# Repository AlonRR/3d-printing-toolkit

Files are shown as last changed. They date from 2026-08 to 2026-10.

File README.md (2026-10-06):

# 3D printing toolkit — profiles, design rules, part verification

Print-process engineering around a single **Prusa MK3S+**, treated as production equipment rather
than a hobby printer. Three things live here:

| | |
|---|---|
| **Tuned slicer profiles** | 20 filament + 10 print + 1 printer preset, every number traced to a vendor datasheet or to a measurement on this machine |
| **Design rules** | FDM constraints calibrated to *this* machine's measured extrusion width, not its nozzle diameter |
| **Part verification** | A pipeline that renders, asserts, checks manifold, slices, and cross-checks a model against the profile it was actually sliced with |

Every figure here is either read out of this repo's own sliced output or measured on the machine.
Where a number is inherited or assumed rather than measured, it says so — that distinction is the
point of most of these documents.

---

## ⚠️ Read this first if you are about to write a profile

**PrusaSlicer does not resolve `inherits` in a hand-written user preset.** Missing keys take the
system *default*, not the parent's value — silently, while slicing still succeeds. A correct preset
has about 85 keys. Full explanation and the fix:
[`slicer/filament/inslogic/README.md`](slicer/filament/inslogic/README.md).

Two more from the same day, each of which cost a round trip:

- **A resolved chain drags `renamed_from` into the child**, so four PETG profiles each ended up
  claiming to *be* the renamed `Generic PET`.
- **`Prusament PETG` excludes 0.6 nozzles** in its compatibility condition, so anything inheriting
  it vanishes from the filament list on a 0.6 — which is why every PETG profile here inherits
  `Generic PETG` instead.

---

## What's in the repo

| Path | |
|---|---|
| [`slicer/filament/inslogic/`](slicer/filament/inslogic/) | Profiles derived from real vendor datasheets — ASA, TPU 95A, PLA Pro, PETG Pro |
| [`slicer/filament/yasin3d/`](slicer/filament/yasin3d/) | A vendor that publishes **no** datasheet. Labelled as a starting point, not a calibration |
| [`slicer/filament/unbranded/`](slicer/filament/unbranded/) | Filament with **no manufacturer at all** — the SKU is its only identity, so the SKU is in the filename |
| [`slicer/filament/ultrafuse/`](slicer/filament/ultrafuse/) | A user copy of a system preset, inherited and not validated here |
| [`slicer/print/`](slicer/print/) | The custom print profiles. ⚠️ One, `…lightning`, has `spiral_vase = 1` baked in — deliberate and documented, but it will surprise you if selected blind |
| [`slicer/printer/`](slicer/printer/) | The printer preset itself |
| [`slicer/reference/`](slicer/reference/) | Vendor data transcribed to Markdown, with what was taken and what was overridden |
| [`scripts/flatten_profiles.py`](scripts/flatten_profiles.py) | Regenerates filament profiles from the vendor chain, because of the `inherits` trap above |
| [`scripts/scad-check.sh`](scripts/scad-check.sh) | Verify a part end to end — render, asserts, manifold, slice — and cross-check its declared parameters against the profile actually used |
| [`scripts/scad-preview.sh`](scripts/scad-preview.sh) | Previews and cross-sections. Sections import the **exported STL**, so an export bug cannot hide behind a correct-looking render |
| [`models/`](models/) | Parametric OpenSCAD sources. The `.scad` is the artefact; STLs are build output and are not tracked |
| [`models/lib/axes.scad`](models/lib/axes.scad) | The xyz arrows **every rendered figure carries** — red +x, green +y, blue +z, the drawn model's own axes — so a reading taken on a part in hand ("0.7 mm loose in x") maps onto the model without guessing |
| [`docs/`](docs/) | The written material — see *Documentation* below |

## What's deliberately *not* here

- **Models and G-code.** STL, 3MF and G-code are large binaries and git is the wrong tool for them.
  `.gitignore` enforces it.
- **Physical-printer configs.** They hold PrusaLink API keys in plaintext. Also gitignored.
- **The parametric CAD library** — a separate project.
- **The heated drybox and desiccant module.** Their documents, firmware and models moved to a
  repository of their own in September 2026, once that work had grown into a project rather than a
  corner of this one. It is not public, so there is no link to give. What stayed here is the material
  the two share: the annealing page, the mechanical-design-review checklist, `scad-check.sh` and
  `scad-controls.sh`.
- **Procurement.** Prices that carry an argument stay; order references, vendors and what was paid
  belong in an inventory system, not a code repo.

---

## Slicer profiles — `slicer/`

**The difference between the vendors is the point.** Inslogic publishes real technical datasheets,
so those profiles derive every temperature, flow and cooling figure from a documented source.
Yasin3D publishes nothing, and one filament here has no manufacturer at all. Those profiles are
generic values with a name attached, and each directory's README records which is which, so nobody
mistakes an assumption for a measurement.

### A defect worth knowing about

The ASA profile asks for a 15 second minimum layer time. **`min_print_speed` silently caps it at
5 seconds** — the slicer does not warn you, and the symptom is poor small-layer cooling that reads
as a temperature problem. [`docs/asa-print-quality.md`](docs/asa-print-quality.md) covers this and
the rest of the ASA tuning, ordered by payoff.

## Design rules — `docs/fdm-design-rules.md`

The governing dimension on this machine is the **0.45 mm extrusion width, not the 0.4 mm nozzle**,
so wall thicknesses quantise to multiples of 0.45. Designing to the nozzle diameter produces walls
the slicer cannot fill cleanly.

The document also records **claims deliberately not imported** from general design advice — wall
steps that assume a 0.4 mm width, bridging figures well past this machine's measured ceiling, and
text-orientation advice that is backwards here. Each is a generic figure meeting a measured one.

## Part verification — `scripts/scad-check.sh`

CI discipline applied to physical parts. For a given model it renders, runs the model's own asserts,
checks the mesh is manifold, slices it, and **cross-checks the model's declared `fdm_*` parameters
against the slicer profile it was actually sliced with** — then exits non-zero on any mismatch. A
part whose design assumptions have drifted from the profile it gets sliced with fails the check
instead of failing on the bed.

## Firmware — moved out

The firmware that lived here moved to repositories of its own in October 2026, each with its history:

- **The enclosure's sensing and airflow** — the chamber node, its measurements and the fan plan:
  [**printer-enclosure**](https://github.com/AlonRR/printer-enclosure).
- **The ESP32-S3 camera node**, in plain ESP-IDF C: `esp32-cam-for-prusa-connect`. It is not public yet;
  it will be once it sends snapshots to Prusa Connect. Until then its code is in this repository's
  history, under `firmware/prusa-cam-c/`.

The particle and VOC/NOx monitor that hangs beside the enclosure is
[**air-quality-monitor**](https://github.com/AlonRR/air-quality-monitor).

## Documentation — `docs/`

| | |
|---|---|
| [`fdm-design-rules.md`](docs/fdm-design-rules.md) | Design rules calibrated to this printer |
| [`openscad-basics/`](docs/openscad-basics/) | Six hands-on OpenSCAD lessons, ending in a part written the way the models here are — every behaviour described was measured, not recalled |
| [`asa-print-quality.md`](docs/asa-print-quality.md) | Getting better ASA prints, ordered by payoff |
| [`annealing-and-hot-service.md`](docs/annealing-and-hot-service.md) | What annealing does and does not do, and why HDT is not a service temperature once a part is loaded |
| [`mk3s-resume.md`](docs/mk3s-resume.md) | Restarting a print the printer has already abandoned |
| [`prusa-connect-api.md`](docs/prusa-connect-api.md) | What the Prusa Connect API can and cannot automate, checked against live endpoints rather than forum posts. Short version: you can read and manage the queue, start prints and read progress — **there is no endpoint to upload a file** |

## Licence

Two licences, because this repository holds two different kinds of work:

| | |
|---|---|
| **Code** — `scripts/` | **MPL-2.0** |
| **Everything else** — `docs/`, `slicer/`, `models/`, this README and the figures | **CC-BY-4.0** |

The split is deliberate. Creative Commons advises against using a CC licence for software: it carries
no patent grant and says nothing about source availability, and a firmware or script consumer needs
both. The rest is documentation, measured profile data and small printable parts, where CC-BY fits and
matches the norm for shared models.

Every file states its own licence, following the [REUSE](https://reuse.software/) specification —
either as an `SPDX-License-Identifier` header or through `REUSE.toml` for files that cannot carry one.
The slicer profiles are in the second group for a concrete reason: PrusaSlicer rewrites a preset when
it saves one and does not preserve comments, so a header written into a profile would vanish the first
time it was edited in the UI. Full licence texts are in [`LICENSES/`](LICENSES/).

⚠️ **Versions published before this change stay CC-BY-4.0.** Everything here was CC-BY-4.0 until
September 2026, and anyone who already has a copy keeps those terms for it. The split applies from
here onward.

---

*Hostnames, addresses and credentials in this repository are placeholders. Machine-specific values
are supplied through ESPHome secrets and are not published here.*

_Parts of this repository were drafted with the help of an LLM agent; reviewed and verified locally._

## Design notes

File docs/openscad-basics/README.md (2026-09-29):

# OpenSCAD basics — six lessons, ending in a part built the way this repository builds them

A hands-on path from nothing to reading and writing the models in [`models/`](../../models/). Each lesson is
a `.scad` file you open, preview, break and fix. Comments explain what you are looking at, and every
lesson ends with a few **TRY** exercises.

Every behaviour the lessons describe was **measured** on the OpenSCAD 2021.01 release and on a 2026
nightly, not recalled. Several things turned out differently from what is commonly said; those are
listed at the end.

## What OpenSCAD is

A program that **describes a solid**. There is no mouse modelling and no undo history: you write
code, OpenSCAD evaluates it into a tree of shapes and operations, and exports the result as a mesh
(STL). Change a number, and the part changes everywhere that number is used.

Two ideas cause most of the early confusion:

- **Names are bound once per scope.** `x = x + 1` does not do what it does in Python — see lesson 3.
- **Geometry is combined, not edited.** You never modify a shape; you union, subtract or intersect
  whole shapes — see lesson 2.

## Setup

**Editor.** Any text editor works. VS Code with an OpenSCAD extension gives syntax highlighting,
completion and hover documentation.

**The loop that makes it pleasant:** open the file in the OpenSCAD application, turn on
**Design → Automatic Reload and Preview**, and edit in your editor. Every save re-previews.

| Key | What it does | When |
|---|---|---|
| **F5** | Preview — fast, approximate | While editing |
| **F6** | Render — computes the real solid | Before exporting an STL, and when a preview looks wrong |

**Read the Console pane.** `echo()` output, warnings and failed asserts appear there, not in the view.

**Which build.** Two are in common use: the **2021.01 release** and the **nightly** snapshots. The
nightly renders far faster, which matters on large models. But when you need to know whether a part
passed its checks, use the release — see *Checking your work*.

## The lessons

| | Lesson | You learn |
|---|---|---|
| 1 | [`01-shapes-and-transforms.scad`](01-shapes-and-transforms.scad) | Primitives, `center`, transforms and why their order matters, and why curves are polygons |
| 2 | [`02-combining-shapes.scad`](02-combining-shapes.scad) | `union` / `difference` / `intersection`, the `#` `%` `!` `*` debug modifiers, cutters that overshoot, parts that only touch, `hull()` |
| 3 | [`03-values-not-variables.scad`](03-values-not-variables.scad) | **The important one.** Why a loop cannot accumulate, scope, `$` variables, and why `0.6 / 0.2 == 3` is false |
| 4 | [`04-modules-and-functions.scad`](04-modules-and-functions.scad) | Modules, functions, `children()`, and `use` versus `include` — with a real library, [`04-library.scad`](04-library.scad) |
| 5 | [`05-loops-lists-and-2d.scad`](05-loops-lists-and-2d.scad) | Ranges, list comprehensions, 2D outlines, `offset()`, `linear_extrude`, `rotate_extrude`, `text()` |
| 6 | [`06-a-real-part/`](06-a-real-part/) | An M3 spacer written the way every model here is: a `.params.scad` settings file, derived values, `assert`s that enforce [`fdm-design-rules`](../fdm-design-rules.md), and a clean pass through `scad-check.sh` |

Do them in order. Lesson 6 uses something from each of the others.

## Checking your work

From the repository root:

```sh
scripts/scad-check.sh docs/openscad-basics/06-a-real-part/m3-spacer.scad
```

That renders the part, runs its asserts, checks the mesh is **one manifold part**, slices it, and
compares the model's `fdm_*` values with the profile it was sliced with. It exits **0** on a pass,
**2** when the model echoed a `WARNING` (it builds, but read why), and **1** when it is blocked.

Measured on lesson 6, each result predicted before running:

| `m3-spacer.params.scad` | Result |
|---|---|
| as shipped | `PASS`, exit 0 |
| `wall = 1.8` | 1 WARNING, exit 2 — four beads, where §1 asks for five |
| `wall = 1.1` | `BLOCKED`, exit 1 — not a whole number of extrusion widths |
| `length = 10.1` | `BLOCKED`, exit 1 — 50.5 layers |
| `length = 10.2` | `PASS`, exit 0 — 51 layers, though `10.2 / 0.2` is not exactly 51 (lesson 3) |

⚠️ **`scad-check.sh` uses the 2021.01 release, and that is deliberate.** On the nightly, a failed
`assert` stopped the build in every simple case tried while writing these lessons — at the top level,
in a module, a function, an `if`, a `for`, and an included file. But in one larger model in a sibling
project, the nightly printed the assertion **and exited 0 with an STL written**, where the release
stopped. The cause was not isolated. So **never read a nightly's exit code as proof that a part
passed** — read its Console, or run the check.

## Resetting a lesson

The lessons are tracked in git, so break them freely:

```sh
git restore docs/openscad-basics/03-values-not-variables.scad
```

`scad-check.sh` leaves an `.stl` and a `.gcode` beside the part. Both are git-ignored.

## Things that turned out differently from what is usually said

Measured while writing these lessons, on both builds:

- **A 3 mm circle at the default settings has five sides.** A pentagon, with 24 % less area than the
  circle asked for — that is an M3 clearance hole. (Lesson 1.)
- **A cutter that stops exactly on a face did not spoil the render.** The flickering skin is a
  *preview* artefact; F6 produced one manifold part of the correct volume. Overshoot anyway, so the
  preview stops misleading you. (Lesson 2.)
- **Solids that touch along a face fused into one part; solids that touch along an edge did not.**
  Only the release warned about the edge case. (Lesson 2.)
- **`0.6 / 0.2` prints as 3 but is not equal to 3.** That is why every layer check here uses a
  tolerance. (Lesson 3.)
- **`offset(r = 2) offset(r = -2)` rounds the outside corners, not the inside ones** — chained
  operations run from the shape outward. (Lesson 5.)

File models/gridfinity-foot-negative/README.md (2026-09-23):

# Gridfinity foot negative

A **negative volume**: the material you remove from a flat-bottomed model to leave a standard
gridfinity foot behind. Not a bin, and not a baseplate.

## Use

In PrusaSlicer: right-click the model → **Add negative volume** → **Load…** → pick an STL, then set
its Z to the bottom of the part. The mesh is centred on X/Y and sits on Z0. Anything of the model
outside the footprint keeps a flat skirt, which is usually what you want.

**The STLs are not in this repo.** `*.stl` is gitignored here by design — the `.scad` is the
source and meshes are generated artefacts. Regenerate them with:

```
openscad -D GridX=1 -D GridY=1 -o gridfinity-foot-negative-1x1.stl gridfinity-foot-negative.scad
openscad -D GridX=4 -D GridY=4 -o gridfinity-foot-negative-4x4.stl gridfinity-foot-negative.scad
```

| variant | footprint | render time |
|---|---|---|
| 1x1 | 42 × 42 × 4.65 mm | ~4 s |
| 4x4 | 168 × 168 × 4.65 mm | ~42 s |

Ready-to-load copies of both live in the OneDrive `Gridfinity` folder alongside the other
gridfinity assets, which is where they are actually loaded from.

`GridX`/`GridY` regenerate any size; `Clearance` defaults to 0 (nominal 42 mm pitch). Raise it to
0.1–0.25 only if prints seat too tightly — this is a negative, so **more clearance removes more
material and leaves a smaller foot**.

## Why it draws strokes where the reference sets cut voids

The profile is taken from `gridfinitybasket.scad` so both produce the same foot, but the solid is
built differently, and the reason is worth keeping.

The basket sweeps the profile around a rounded rectangle with `sweep_rounded()`. That works, and it
leaves **50 non-manifold edges** where the four wall segments meet the four corner `rotate_extrude`s.
Here each section of the profile is a `hull()` between two `offset()` rounded squares instead. A
rounded square is convex and the hull of two parallel convex profiles is a convex frustum, so every
section is manifold by construction — measured, both STLs export as closed meshes with **zero**
non-manifold edges.

The cross-section at any height is just the 34 mm core square offset outward by the profile's x at
that height, which is what makes the `offset()`/`hull()` construction exact rather than an
approximation of the swept version.

## Verified

The claim under test is not "it renders" but "subtracting this from a flat box yields a gridfinity
foot" — a negative that is inverted, offset or the wrong height still renders fine.

Predicted before measuring: the 1x1 box is 42 × 42 × 4.65 = **8202.600 mm³** and the negative
measures **1291.384 mm³**, so a correct complement must leave a foot of exactly **6911.216 mm³**.
Rendering *box minus negative* gives 6911.216 mm³ and matches a directly-rendered foot vertex for
vertex (identical sorted vertex sets; only facet normals differ). The 4x4's volume is 16.0000× the
1x1's, so the tiling has no overlap and no gap.

Note that the bounding box **cannot** discriminate here — the foot is 42 × 42 at its top and the
negative is 42 × 42 throughout, so both share the same box. The volume is what carries the test.

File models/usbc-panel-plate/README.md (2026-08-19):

# USB-C panel plate

A printed plate covering an oversized rectangular aperture in a PC case front
panel, around a commodity IP67-style **panel-mount USB-C feedthrough** (moulded
black flange, raised rounded-rect boss around the port, one screw hole per side).

Source is split like C:

| File | |
|---|---|
| [`usbc-panel-plate.params.scad`](usbc-panel-plate.params.scad) | **the header** — every value you SET, and nothing else. No geometry, no derived values |
| [`usbc-panel-plate.scad`](usbc-panel-plate.scad) | **the body** — derived values, modules, geometry, echoes, guards. Render this one |
| [`draw2d.scad`](draw2d.scad) | drafting primitives — dimension lines, leaders, arrowheads, dashed runs. Shared by both diagrams |
| [`parameter-map.scad`](parameter-map.scad) | → `parameter-map.png`, the dimensioned drawing of every parameter |
| [`flange-check.scad`](flange-check.scad) | → `flange-check.png`, the open measurement question. See "Retention" |

Every parameter is a named variable, tagged MEASURED or <<CONFIRM>>.

```
        raised rectangle (14.4 x 6.1)
   +---------------------------------------+
   |          .-------------.              |
   |   O      |   [=====]   |      O       |   23.9 x 15.0 x 2.4 mm
   | screw    '-------------'    screw     |
   |            notch top/bottom           |
   +---------------------------------------+
        |<--- screw span 19.8 c-to-c --->|
```

> **Every number below is regenerated from the model's own echo block.**
> Do not hand-edit them — re-render and paste. Hand-edited numbers drift, and a
> drifted table reads exactly as authoritative as a correct one.

## Current geometry

```
plate              : 23.9 x 15 x 2.4 mm
  width set by     : FASTENERS (23.9) - coverage alone would allow 23.4   [screw_style hole]
covers opening     : 23.4 x 15 mm, lap 0 mm (corner floor 0.43934)
port opening       : 9.6 x 3.9 mm as cut
port recess        : 2.3 mm a plug must reach in (lip 0.8 + protrusion 1.5)
rear pocket        : 14.2 x 8.8 mm as cut, 1.2 mm deep, 0.25 mm/side clearance on the boss
max boss height    : 1.8 mm from the connector flange (pocket 1.2 + panel 0.6)
two-bridge trick   : ON -- 3 staged layers of 0.2 mm
  L1 two bridge    : slot 9.6 x 8.8  -> two strips spanning 8.8 mm, anchored both ends
  L2 rectangle     : 9.6 x 3.9 square  -> the other two sides bridge 9.6 mm
  L3 rounded       : r2 fillets only, laid on the solid rectangle below
web beside pocket  : 1.2 mm
web above/below    : 3.1 mm
outboard of screw  : 0.45 mm
protrusion         : 14.4 x 6.1 x 1.5 mm on the front
  frame beside port: 2.4 mm
  frame over/under : 1.1 mm
  prot -> screw    : 1.1 mm
notch              : r 1.8 mm (1.95 as cut) at x = 0
  notch -> pocket  : 1.15 mm
  notch -> screw   : 8.87014 mm
  lap left at notch: -1.95 mm
screws land on     : OPEN AIR - plate clamps to the connector, not to the panel - and with overlap 0 there is no lap, so the panel is not trapped at all
WARNING: overlap 0 - the plate is no larger than the aperture, so NOTHING in front of the panel is wider than the hole. The connector flange behind can still stop it pulling OUT, but nothing stops the assembly being pushed IN - which is the direction a plug loads it
WARNING: outboard of screw 0.45 mm is under 3 perimeters (1.35) as cut - a screw pulls directly on this and it will split
WARNING: notch reaches 1.95 mm past the aperture edge - it opens a gap straight into the case across its whole chord, and removes any lap there was to retain the plate at that edge
warnings           : 3 - the part will build, read them
```

## Dimension provenance

| Parameter | Value | Basis |
|---|---|---|
| `gap_w` × `gap_h` | **23.4 × 15.0** | **MEASURED** — the case aperture |
| `panel_t` | **0.6** | **MEASURED** — case sheet thickness |
| `screw_span` | **19.8** | **MEASURED** — see derivation below |
| `screw_d` | **2.9** (M2.5) | **MEASURED** — see derivation below |
| `boss_h` | **8.0** | **MEASURED** |
| `prot_w` × `prot_h` | **14.4 × 6.1** | **MEASURED** |
| `boss_w` | 13.4 | ⚠️ **NOT measured** — photo-scaled, and it feeds the fit |
| `prot_t` | 1.5 | ⚠️ **NOT measured** |
| `overlap` | **0** | chosen deliberately — the fitting is space-limited. See "Retention" |
| `plate_t` | 2.4 | chosen — whole layers, see "layer alignment" |
| `port_w` × `port_h` | 9.3 × 3.6 | chosen to hug the 8.94 × 3.16 receptacle shell |

### Screw pattern derivation

```
inner edge to inner edge = 16.90 mm
outer edge to outer edge = 22.70 mm

centre-to-centre = (16.90 + 22.70) / 2 = 19.80 mm
hole diameter    = (22.70 - 16.90) / 2 =  2.90 mm   -> M2.5, not M2
```

## Nominal vs as-cut

Every cut is grown by `fdm_hole_comp` (0.15 mm/side) to compensate for printed holes
coming out undersize. **Every echo and assert is therefore computed from the
grown values, not the nominal ones.** This matters more than it sounds. Auditing
nominal dimensions while cutting compensated ones reports every clearance
0.15–0.30 mm better than the part actually has: a screw edge distance of 0.40 mm
reads as 0.55 — under one extrusion, on the feature most likely to break, and on
the wrong side of the perimeter floor.

The as-cut names (`pw`, `ph`, `bw`, `bh`, `sd`, `nr`, `cbd`) are defined once at
file scope and used by the geometry, the echoes and the guards alike.

`boss_clear` is separate and deliberate: `fdm_hole_comp` only cancels shrink, which
for a pocket means printing *line-to-line* on the boss. Fit needs its own
allowance, so the pocket gets 0.25 mm/side on top.

## Retention

The aperture is 23.4 mm wide; the screws span 22.70 mm outer-to-outer. Both
screws therefore pass through **open air**, not sheet metal. The plate bolts to
the *connector*, not to the panel.

That leaves the panel held only by what is larger than the hole on each side of
it, and the two directions are **not** symmetric:

| Direction | What stops it | Status at `overlap = 0` |
|---|---|---|
| assembly pulled **OUT**, forward | the connector's flange, behind the panel | works — *if* that flange exceeds 23.4 × 15 (**unmeasured**) |
| assembly pushed **IN**, backward | the plate's lap, in front of the panel | **nothing** — the plate is no larger than the hole |

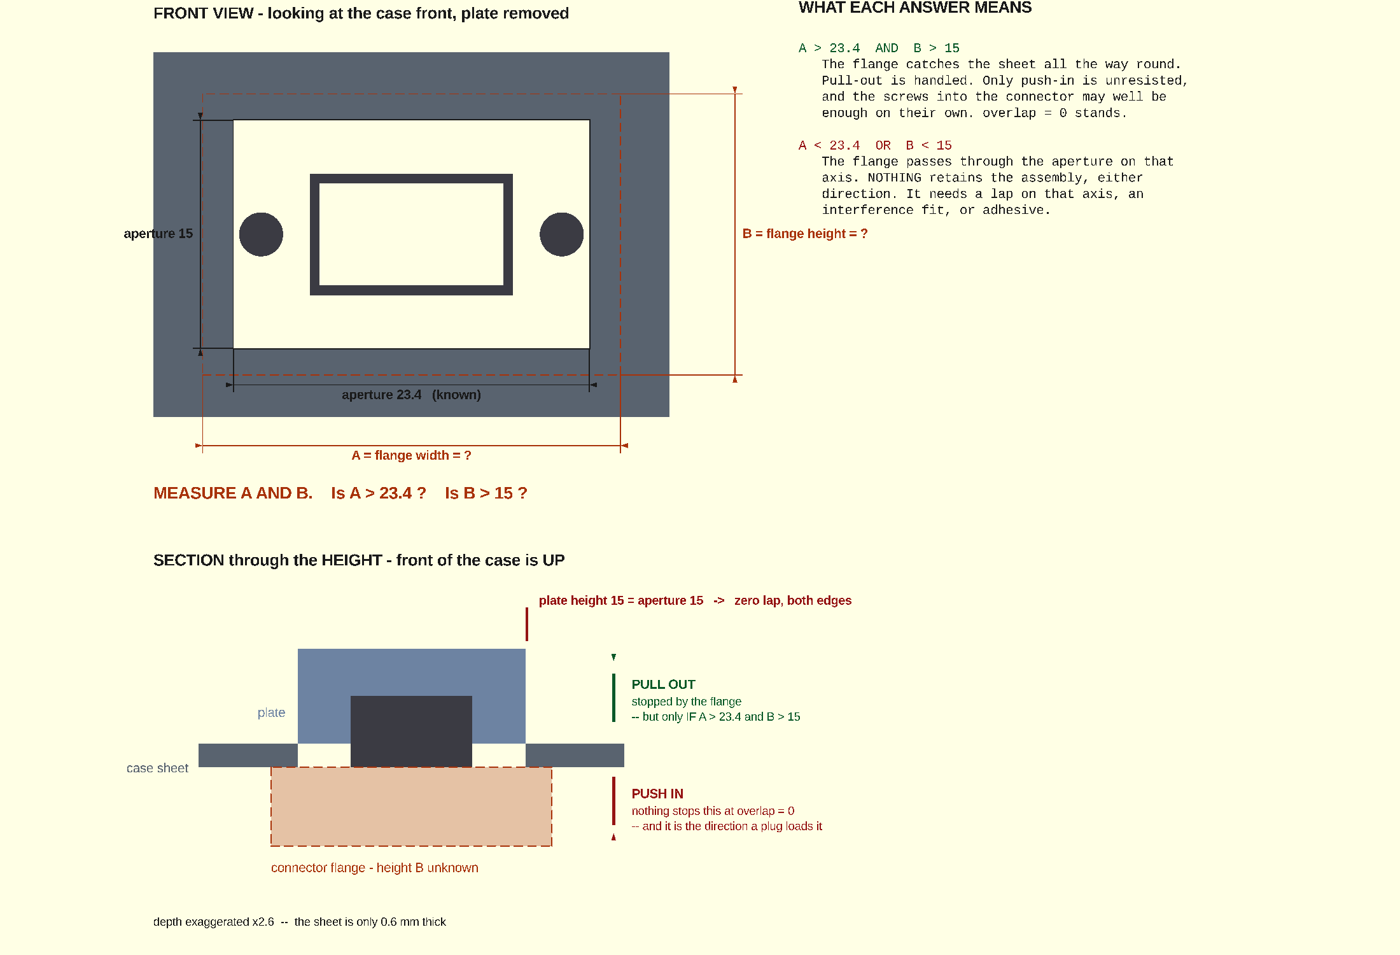
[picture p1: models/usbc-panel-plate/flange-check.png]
what to measure


`flange-check.png` states the open question: measure the connector flange's
**A** (width) and **B** (height) and compare against 23.4 × 15. Solid lines on
that drawing are values the model knows; dashed and orange are the unknown.

`overlap = 0` is deliberate: the fitting is space-limited and the plate cannot
grow. The cost is the second row, and push-in is the direction a plug loads it.
The guard states exactly that rather than calling it a failure.

A **rear flange on the plate does not fix this.** Trapping a sheet needs material
on both faces of it; a rear flange sits on the same side as the connector flange,
so the assembly can still travel inward. Only something in *front* wider than the
aperture — or friction/adhesive — resists push-in.

Two guards cover the geometry, and they are deliberately separate because they
describe different failures:

- **No lap at all** (`overlap <= 0`) — nothing in front of the panel is wider
  than the hole. Independent of `corner_r`.
- **Corners only** (`corner_r > 0 && 0 < overlap <= corner_r * (1 - 1/sqrt(2))`)
  — the straight edges cover but the *rounded corners* fall inside, leaving four
  open gaps. Not obvious from the edge arithmetic.

Testing `overlap <= corner_min` alone conflates them, and degenerates at
`corner_r = 0`: `corner_min` is 0, the condition reads `0 <= 0`, and it reports
rounded corners falling inside on a plate that has no rounded corners.

**The notches cut past the aperture edge** by 1.95 mm. At `overlap = 0` there is
no lap left for them to remove, so the warning states what is actually true — an
open gap into the case across the notch chord — rather than asserting a lap that
does not exist.

## Layer alignment

`plate_t = 2.4`, not 2.5. At `fdm_layer_h = 0.2` that puts the pocket floor and
all three staged layers at print z **1.2 / 1.4 / 1.6 / 2.4** — every one on-grid.
At 2.5 mm they all land mid-layer and the staging resolves on a slicer tie-break
rather than on the geometry. Asserted.

## Slicer facts are named `fdm_*`

`fdm_layer_h`, `fdm_extrusion_w` and `fdm_hole_comp` are facts about how the part
gets **made**, not decisions about what it should **be**. Each has a counterpart
in the print profile, and the model is wrong the moment they disagree — so they
are grouped and prefixed to make that obvious at a glance rather than discovered
by a bad print.

The wall thresholds are derived from them rather than written down:

```scad
perim2 = 2 * fdm_extrusion_w;   // 0.90 — minimum for a non-load feature
perim3 = 3 * fdm_extrusion_w;   // 1.35 — minimum for anything that takes force
```

Spelled as the literal `1.35`, with "3 perimeters" explained in the assert
message, it would be a magic number whose meaning lives somewhere nothing can
check it. Derived, the guards move with the profile. Verified by overriding
them:

```
-D fdm_extrusion_w=0.8   -> "web ... is under 2 perimeters as cut"   (fires)
-D fdm_layer_h=0.15      -> "lip_t is not a whole number of layers"  (fires)
```

## The two-bridge trick — three staged layers

Printed back-face-down, the layer closing over the pocket **is the lip, and the
lip has the port hole in it**. That is not a plain bridge — the printer would be
drawing the hole outline in mid-air.

It is split across three layers, and the point is that **each layer does exactly
one thing**. No layer has to lay a straight run and a curve in the same pass.

```
  L1  THE TWO BRIDGE   slot 9.6 x 8.8  -> two strips spanning 8.8 mm,
                                          each anchored at BOTH ends
  L2  THE RECTANGLE    9.6 x 3.9 square -> the other two sides bridge 9.6 mm
                                          onto those strips
  L3  THE CORNERS      r2 fillets only  -> laid on the solid rectangle below

     L1                 L2                 L3
  +--+      +--+     +--+------+--+     +--+------+--+
  |  |      |  |     |  |      |  |     |  /      \  |
  |  |  gap |  |     |  | rect |  |     |  | port |  |
  |  |      |  |     |  |      |  |     |  \      /  |
  +--+      +--+     +--+------+--+     +--+------+--+
```

Both spans are under the ~10 mm ceiling and both are asserted. So is the thing
that makes the staging meaningful: if the slot were no taller than the port, L1
and L2 would be the same shape; if `port_r` were 0, L2 and L3 would be. Either
way the render still succeeds while silently doing less than it claims.

**Nothing is sacrificial.** All three layers are load-bearing geometry, nothing
is snipped or drilled afterwards, and the sliced G-code carries
`support_material = 0`. House rule: prefer no support, prefer permanent over
sacrificial, and read "this needs a sacrificial feature" as a sign a better
design exists. See [`docs/fdm-design-rules.md`](../../docs/fdm-design-rules.md)
§3b–3c.

## Printing

**Back face down.** `flip_for_print` rotates the model 180° about X on export,
so the STL arrives already oriented — do **not** flip it again in the slicer.
Front-face-down puts the protrusion on the bed and leaves the plate rim
overhanging ~4.6 mm in mid-air.

The `lead_in` chamfer consequently sits on the **top** face. It is a plug lead-in
only; it does not relieve elephant's foot, which is a first-layer effect. The
`pocket_chamfer` is the one on the bed face, where a chamfer is free.

## Guards

Two kinds, and the distinction is deliberate.

| | Count | Meaning | Behaviour |
|---|---:|---|---|
| **BLOCK** — `assert` | 12 | the geometry is impossible or self-contradictory: a feature vanishes, inverts, or cuts the part in two | render stops |
| **WARN** — `echo "WARNING: …"` | 15 | it builds and prints, but is compromised: a wall under the perimeter floor, a notch into the case, a stage landing mid-layer | STL still produced |

Accepting a thin wall is the operator's call, so it warns. Producing a part with
no lip at all is not a call, so it blocks. `scad-check.sh` mirrors the split —
exit 1 for blocked, exit 2 for builds-with-warnings.

Coverage of the non-default branches is deliberate: `prot_face = "back"`,
`cbore_d > 0`, `prot_t = 0`, `bridge_slot = false`, `screw_style = "slot"` and
`flip_for_print = false` all render clean and manifold. `prot_face = "back"`
fails loudly rather than silently printing the protrusion as two slivers.

## Regenerating

```sh
openscad -o usbc-panel-plate.stl usbc-panel-plate.scad
```

Previews, cross-sections and thin slices:

```sh
sh ../../scripts/scad-preview.sh usbc-panel-plate.scad out 1.2 1.4 1.6
```

STL output is gitignored (repo convention — binaries live in
`OneDrive\3D printing\`); the `.scad` is the artefact worth keeping.

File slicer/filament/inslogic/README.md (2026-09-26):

# Inslogic filament profiles — Prusa MK3S+

PrusaSlicer filament profiles for **Inslogic ASA**, **TPU 95A**, **PLA Pro** and **PETG Pro**,
built from Inslogic's own Technical Data Sheets (all rev. 12.02.2024). The figures are
transcribed in [`../../reference/inslogic-filament-data.md`](../../reference/inslogic-filament-data.md);
the PDFs themselves are Inslogic's and are not redistributed here.

Inslogic's [download center](https://www.inslogic3d.com/pages/download-center) publishes
**TDS/SDS data sheets only — no slicer profiles**, for any slicer. These were derived from
the data sheets by hand.

**Name the grade, not the material.** Inslogic sells eight different PLA products — PLA Pro,
Matte, Silk PLA+, Silk Dual/Tri/Four Colour, High-Speed Marble, Nebulux, LW-PLA and WoodFill
— and two PETGs, PETG Pro and the carbon-filled PETG-CF10. Each has its own data sheet.
These profiles cover the plain **Pro** grades only, which is why they are named
`Inslogic PLA Pro` and not `Inslogic PLA`: if the spool on the shelf turns out to be Matte or
Silk, the profile name is what surfaces the mismatch before the print does.

> **Print-validated: `Inslogic ASA - thin wall` (29 Jul) and `Inslogic TPU 95A - fast` (30 Jul).**
> The rest are installed and slice correctly, but their *temperatures* are still derived from
> the data sheet rather than validated against a printed part. Treat those as a well-reasoned
> starting point.

## ⚠️ Hand-written presets MUST be flattened — `inherits` does not fill the gaps

**The single most important thing in this folder.** It broke every profile here silently, and
the failure is invisible to normal checks.

PrusaSlicer records `inherits` for the UI ("modified from X") but does **not** consult the
parent to supply missing keys when loading a user preset. Any key absent from the file takes
the **system default**, not the parent's value. A PrusaSlicer-written preset has **85 keys**;
the sparse `inherits` + overrides files originally written here had 16–22, so ~68 keys per
profile were silently wrong.

What was actually lost, none of it visible in a temperature check:

- **`start_filament_gcode`** — the `M900 K` **Linear Advance** calibration. Reduced to a bare stub.
- `filament_ramming_parameters` — generic instead of ASA/FLEX-specific
- `filament_retract_length` / `_speed`, `extrusion_multiplier`, `cooling_slowdown_logic`

The trap is that slicing *succeeds* and the keys you personally wrote all read back correctly,
so a spot-check passes. The tell is the key count, or a key the parent sets that you didn't.

**Regenerate with `flatten_profiles.py`** (kept alongside these files). It resolves the real
chain out of `PrusaResearch.ini` with precedence: reference template < resolved parent chain <
your explicit overrides. Sparse originals are preserved as `*.ini.sparse-bak`.

Quick check that a preset is sound:

```powershell
Get-ChildItem "$env:APPDATA\PrusaSlicer\filament\*.ini" | ForEach-Object {
  "{0,-32} {1,3}" -f $_.BaseName, (Get-Content $_.FullName | Where-Object { $_ -match '^[a-z_0-9]+ = ' }).Count
}
# anything well under ~85 is sparse and silently running on defaults
```

Two things leak *into* a flattened preset that should not, both found on 29 Aug 2026 while
building the PETG profiles:

- **`renamed_from`.** `Generic PETG` carries `renamed_from = "Generic PET"`, a vendor-bundle
  migration key. Resolving the chain drags it into the child, so every PETG profile built this
  way claimed to *be* the renamed `Generic PET` — four of them at once. `flatten_profiles.py`
  now strips it, the same way it strips `inherits`.
- **A parent compatibility condition you didn't read.** `Prusament PETG` sets
  `nozzle_diameter[0]!=0.6` on top of the usual `!=0.8`, so anything inheriting it silently
  vanishes from the filament list on a 0.6 nozzle — which Inslogic's sheet explicitly
  supports. `Generic PETG` has no such clause. That is the *only* reason the PETG profiles here
  inherit Generic rather than Prusament; the two are otherwise identical apart from temperature
  and price, both of which get overridden anyway.

And one thing the key-count check will show that is *not* a fault: a preset PrusaSlicer has
itself rewritten can come back with **more** than 85 keys. The installed `Inslogic ASA` read 87
on 29 Aug 2026 — 2.9.4 had added `filament_flush_speed` and `filament_flush_volume` when it last
saved the file. That is upstream drift, not sparseness; **the number to be alarmed by is a low
one.** (Reinstalling from this folder later that day put it back to 85. Both keys are
multi-material flushing settings, irrelevant on a single-extruder MK3S+, and PrusaSlicer re-adds
them on its next save.)

## `Inslogic TPU 95A - fast` — the flow ceiling was the profile, not the filament

Prusa rates `Generic FLEX` / `Ultrafuse TPU-95A` at **1.2 mm³/s** on MK3-family printers, but
rates the genuine high-speed grades — **NinjaTek Cheetah TPU (95A)** and **Overture High Speed
TPU** — at **4.0 mm³/s**. This profile inherits Cheetah to borrow that ceiling *and* its 1.5 mm
retraction (`Generic FLEX` uses 0), then applies Inslogic's TDS temperatures.

Tested on `VaseRose_5cm`, 30 Jul 2026:

| Profile | mm³/s | Retraction | Print time |
|---|---|---|---|
| `Inslogic TPU 95A` | 1.2 | 0 | 2 h 53 m |
| **`Inslogic TPU 95A - fast`** | **4.0** | **1.5 mm** | **1 h 40 m** — 1.73× faster ✅ |

**Standard Inslogic TPU 95A sustains 4.0 mm³/s on this MK3S+** — clean, no under-extrusion, no
grinding. So a dedicated high-flow grade is **not** needed on speed grounds.

### What a flow cap is worth in mm/s — and the cross-section that converts it

**An extrusion is not a rectangle.** PrusaSlicer models the bead as a rectangle with
semicircular ends, so at `0.45 × 0.2 mm` the cross-section is

    0.2 × (0.45 − 0.2) + π × 0.1² = **0.0814 mm²**

not the 0.090 mm² that width × height suggests — a 10 % error, always in the direction of
*understating* the speed a given flow cap buys. (This paragraph said 0.090 mm² and 44 mm/s until
29 Aug 2026.)

So 4.0 mm³/s buys **49 mm/s**, which sits just *above* this machine's `perimeter_speed = 45`
and well below its 80 mm/s infill.

**Measured, not derived.** Slicing a solid 40 mm cube with this profile emits perimeters at the
full 45 mm/s and infill throttled to exactly **49.1 mm/s**; the stock 1.2 mm³/s profile throttles
everything to **14.7 mm/s**. Both match the formula to three figures, which is what makes the
0.0814 the right number and the 0.090 the wrong one.

The cap therefore binds on infill only — hence 1.73× rather than the 2.16× a thin swatch
predicted. Expect larger gains on infill-heavy parts.

### The same arithmetic for everything else on the shelf

At 0.4 nozzle, 0.2 mm layers, 0.45 mm width:

| Filament | Cap | Top speed it permits | Binds anything in these print profiles? |
|---|---|---|---|
| `Inslogic PLA Pro` | 15 mm³/s | 184 mm/s | No |
| `Inslogic ASA` | 11 mm³/s | 135 mm/s | No |
| `Inslogic PETG Pro` | 8 mm³/s | 98 mm/s | No |
| `Inslogic TPU 95A - fast` | 4.0 mm³/s | 49 mm/s | Infill only |
| `Inslogic TPU 95A` | 1.2 mm³/s | 15 mm/s | Everything, first layer included |

The fastest move any print profile in this repo asks for is **80 mm/s infill, which needs only
6.5 mm³/s**. That is why a solid 40 mm cube takes **1 h 37 m in PLA, ASA *and* PETG — the three
finish within six seconds of each other** (measured 29 Aug 2026). Their flow ceilings are real
but dormant, and the ranking PLA > ASA > PETG only wakes up past ~98 mm/s, where PETG throttles
first.

TPU is the only filament here whose ceiling is doing anything: the same cube is 1 h 39 m on
`- fast` (+3 %) and **3 h 54 m on the stock profile — 2.4×**.

**Not established:** whether 4.0 is the real limit. It was borrowed from Cheetah's rating, not
found by testing this filament to its edge.

## `Inslogic ASA - thin wall` — the one that's been proven on a real print

Built 28 Jul 2026 after a vase-mode stem (21.8 mm tube, 147 mm tall, single wall, 727 layers)
printed non-uniform on its rear face using the general-purpose `Inslogic ASA` profile.

Measured from the sliced G-code, before and after:

| | Layer time | Speed | Fan | Nozzle | Print time |
|---|---|---|---|---|---|
| `Inslogic ASA` | 5.01 s | 13.7 mm/s | 20 % | 255 °C | 1 h 12 m |
| `Inslogic ASA - thin wall` | **10.01 s** | 6.8 mm/s | **70 %** | 250 °C | **2 h 09 m** |

**Result: markedly better.** ✅

**What that proves — and what it doesn't.** Three things changed at once (fan, layer time,
temperature), so which one carried the fix isn't isolated. The *direction* is conclusive
though: more cooling plus more solidification time improved it. Had a draft through the
enclosure's open vent side been **over**-cooling the rear face, tripling the fan would have
made it worse. It didn't. So the cause was **under-solidification** — ASA at 255 °C landing on
a bead ~5 seconds old that hadn't set — and the draft theory is ruled out as the primary cause.

Also settled: **70 % fan did not cause the ASA layer-bonding failure** that was the risk of
going that high. The 50 % fallback noted in the profile isn't needed.

Worth remembering for next time: the Inslogic TDS specifies **100 % fan**, and the
general-purpose profile deliberately overrides that to 20 % to stop warping on bulk ASA. For a
single wall with no cross-section to delaminate, the data sheet was closer to right than the
override was.

**A fourth change, found 29 Aug 2026 and missing from the list above: `min_print_speed` went
15 → 5.** It is the change that made the 10 s layer time possible at all — with a 15 mm/s floor,
this part's 67 mm loop cannot take longer than **4.5 s** however long you ask for. Which also
means the general-purpose `Inslogic ASA` profile had been requesting a 15 s minimum layer time
and getting 5, on exactly the small parts that need it most.

**Fixed the same day:** `min_print_speed = 5` is now an explicit override in `Inslogic ASA` and
`Inslogic ASA @0.8 nozzle`. On the tube geometry above that takes the layer from 4.47 s to
13.41 s; on a 40 mm cube and a mid-size part it changes the print time by nothing at all, since
their layers never reach the floor. Worked through in
[`docs/asa-print-quality.md`](../../../docs/asa-print-quality.md).

## `Inslogic PLA Pro` and `Inslogic PETG Pro` — one rule, two deviations

Added 29 Aug 2026 from the PLA Pro and PETG Pro data sheets. Both are the plain grades sold by
[filamentcenter.co.il](https://filamentcenter.co.il/), Inslogic's Israeli distributor:
**PLA Pro ₪59/kg** and **PETG Pro ₪49/kg**, incl. VAT, checked 29 Aug 2026. Those are the
numbers in `filament_cost`.

### The rule the temperatures follow

Inslogic states nozzle temperature as **speed-dependent bands**, not a single number, so the
only real decisions are which band this printer sits in and where in it to land:

> **Print temperature = the top of the TDS band for the throughput this printer actually runs.
> First layer = whatever the Prusa parent does relative to that, as long as the result is still
> a temperature the sheet sanctions somewhere.**

The reason to trust that rule is not that it sounds tidy — it is that applying it reproduces
the ASA and TPU choices already made in this folder, months earlier and by hand.

| Profile | Band used | Print | First layer | Why that first layer |
|---|---|---|---|---|
| `Inslogic PLA Pro` | 195–205 °C @ 50–100 mm/s | **205** | **210** | Parent does +5, and 210 is inside the sheet's faster band |
| `Inslogic PLA Pro @0.8 nozzle` | 205–220 °C @ 100–300 mm/s | **220** | **220** | Parent's 230 is above anything the sheet sanctions → **clamped** |
| `Inslogic PETG Pro` | 230–240 °C @ 50–100 mm/s | 240 | 240 | Parent already sits exactly there — no override in the file |
| `Inslogic PETG Pro @0.8 nozzle` | 240–255 °C @ 100–300 mm/s | 250 | 240 | Parent runs the first layer *cooler* at 0.8; that is Prusa's own choice for PETG and 240 is the top of the slow band, so it stands |

A 0.8 nozzle moves roughly four times the material per second at the same head speed, which is
why it reads against the faster band even though the head is not moving faster. Same reasoning
as `Inslogic ASA @0.8 nozzle`.

Note what the rule produces for PETG: **nothing**. Both PETG profiles override no temperature
at all, because Prusa's Generic PETG chain already lands on the vendor's numbers. A profile
that changes less than expected is the good outcome, not a sign the work was skipped.

### Deviation 1 — PETG fan stays at 30/50 %, not the sheet's 100 %

The ASA judgment call below calls the sheet's 100 % "what reads like a template default." With
four sheets in hand it is no longer a suspicion: **ASA, TPU 95A, PLA Pro and PETG Pro all say
100 %** — four materials whose cooling needs are nothing alike, one number. It is boilerplate.

PETG therefore keeps Prusa's 30 % min / 50 % max, because heavy part cooling is the standard
way to destroy PETG layer adhesion. **PLA is the one material where the 100 % is right**, and
there the parent already runs 100 %, so no fan override appears in that file either.

### Deviation 2 — PETG bed at 70 °C, against Prusa's 85/90

Inslogic says 60–70 °C; Prusa's PETG profiles run 85 °C first layer / 90 °C. These profiles
take the vendor's ceiling, **70/70** — the same "hottest the vendor sanctions" logic as the ASA
bed below, but with a second argument the ASA case does not have: **PETG bonds to smooth PEI
above roughly 85 °C hard enough to tear PEI off the sheet on removal.** Here the
vendor-faithful number is also the one that protects the sheet.

If the first layer will not stick at 70 °C, raise toward 85/90 — and lay down a thin glue-stick
release layer first. The glue is what makes the hotter bed *safe*; it is not what makes it
work.

---

## Status

ASA and TPU installed 28 Jul 2026; PLA Pro and PETG Pro **29 Aug 2026**. All copied into
`%APPDATA%\PrusaSlicer\filament\` and verified end-to-end: each slices a real part with exit 0
and the G-code carries the intended temperatures and the `M900` Linear Advance line.

| Profile | Nozzle °C | Bed °C | Fan min/max | Max vol. | Density | ₪/kg |
|---|---|---|---|---|---|---|
| `Inslogic ASA` | 255 | **105 / 110** | 20 / 20 | 11 | 1.05 | 69 |
| `Inslogic ASA @0.8 nozzle` | 265 | **105 / 110** | 20 / 20 | 15 | 1.05 | 69 |
| `Inslogic ASA - thin wall` | 250 | 100 | 70 / 70 | 11 | 1.05 | 69 |
| `Inslogic ASA - thin wall, flat base` | 250 | 100 | 70 / 70 | 11 | 1.05 | 69 |
| `Inslogic TPU 95A` | 210 | 50 | 100 / 100 | 1.2 | 1.23 | 79 |
| `Inslogic TPU 95A @0.8 nozzle` | 215 | 50 | 100 / 100 | 4.3 | 1.23 | 79 |
| `Inslogic TPU 95A - fast` | 225 | 50 | 100 / 100 | 4.0 | 1.23 | 79 |
| `Inslogic PLA Pro` | 205 (first 210) | 60 | 100 / 100 | 15 | 1.20 | 59 |
| `Inslogic PLA Pro @0.8 nozzle` | 220 | 60 | 100 / 100 | 15 | 1.20 | 59 |
| `Inslogic PETG Pro` | 240 | 70 | 30 / 50 | 8 | 1.26 | 49 |
| `Inslogic PETG Pro @0.8 nozzle` | 250 (first 240) | 70 | 30 / 50 | 20 | 1.26 | 49 |

### Prices — fixed 29 Aug 2026, and the reason they were wrong

The four PLA/PETG profiles were built with a real price in them. The seven older ASA and TPU
ones **never set `filament_cost` at all**, and so silently carried whatever their Prusa parent
charged:

| Profile | Was | Where that number came from | Now |
|---|---|---|---|
| all four ASA | ₪35.28 | `Prusament ASA` | **₪69** |
| `Inslogic TPU 95A` (+ @0.8) | ₪82 | `Generic FLEX` | **₪79** |
| `Inslogic TPU 95A - fast` | ₪85 | `NinjaTek Cheetah TPU` | **₪79** |

ASA was costing out at roughly **half** what the spool actually costs. The TPU numbers looked
plausible — 82 and 85 against a real 79 — which is worse than being obviously wrong: a
believable inherited number reads as a deliberate one. The tell was that **all three TPU files
disagreed with each other** while none of the three matched a price anyone had ever paid.

Real prices are Inslogic's Israeli distributor,
[filamentcenter.co.il](https://filamentcenter.co.il/), checked 29 Aug 2026, per 1 kg spool
incl. VAT: **ASA ₪69 · TPU 95A ₪79 · PLA Pro ₪59 · PETG Pro ₪49**.

`filament_cost` is now an explicit override in every sparse master here, so it can no longer be
supplied by a parent without anyone noticing. The general rule: **a key you never set is not a
key with no value.**

Verified with, e.g.:

```powershell
& "C:\Program Files\Prusa3D\PrusaSlicer\prusa-slicer-console.exe" --export-gcode `
  "$env:USERPROFILE\OneDrive\3D printing\usefull\3030-m3-v2.stl" `
  --printer-profile "Original Prusa i3 MK3S & MK3S+ 0.8 nozzle" `
  --print-profile  "0.40mm QUALITY @0.8 nozzle - NO Skirt" `
  --material-profile "Inslogic ASA @0.8 nozzle" `
  --output "$env:TEMP\test.gcode"
```

### Reinstalling (after editing the copies here)

PrusaSlicer rewrites its config folder on exit, so **close PrusaSlicer first** — otherwise
the running instance overwrites the new files when you quit it.

```powershell
Copy-Item "$env:USERPROFILE\Tools\3d-printing\slicer\filament\inslogic\*.ini" `
          "$env:APPDATA\PrusaSlicer\filament\"
```

The 0.4 profiles show up for any nozzle except 0.8; the `@0.8 nozzle` ones only when the
printer profile is set to 0.8. That's inherited from the parent profiles' compatibility
conditions — it's why each material needs two files rather than one.

---

## What the data sheets actually say

| | **ASA** | **TPU 95A** | **PLA Pro** | **PETG Pro** |
|---|---|---|---|---|
| Diameter | 1.75 ± 0.02 mm | 1.75 ± 0.03 mm | 1.75 ± 0.02 mm | 1.75 ± 0.02 mm |
| Density | 1.05 g/cm³ | 1.23 g/cm³ | 1.20 g/cm³ | 1.26 g/cm³ |
| **Drying** | **80 °C, 4 h** | **50 °C, 4 h** | **50 °C, 4 h** | **50 °C, 4 h** |
| Nozzle sizes | 0.2 / 0.4 / 0.6 mm | 0.4 / 0.6 mm | 0.2 / 0.4 / 0.6 mm | 0.2 / 0.4 / 0.6 mm |
| Nozzle temp | 250–260 °C @ 50–100 mm/s<br>260–280 °C @ 100–200 mm/s | 190–210 °C @ 50–80 mm/s<br>210–230 °C @ 80–120 mm/s | 195–205 °C @ 50–100 mm/s<br>205–220 °C @ 100–300 mm/s | 230–240 °C @ 50–100 mm/s<br>240–255 °C @ 100–300 mm/s<br>255–270 °C @ 300–600 mm/s |
| Bed temp | 80–100 °C | 50–60 °C | 50–60 °C | 60–70 °C |
| Bed type | Smooth PEI / high-temp plate | **Textured PEI** / cool plate | **Textured PEI** / cool plate | Smooth PEI / high-temp plate |
| **Cooling fan** | **100 %** | **100 %** | **100 %** | **100 %** |
| Other | Tg 108 °C · HDT 98 °C · shrinkage 0.4–0.9 % | Shore 95A · HDT 53 °C · elongation 1050 % | Tg 65.3 °C · HDT 55 °C · tensile 56 MPa · Izod 20.1 kJ/m² | Tg 65.5 °C · HDT 72 °C · tensile 50 MPa · Izod 4.8 kJ/m² |

**Read the cooling-fan row across.** Four materials — a warp-prone styrenic, a soft elastomer,
a PLA and a PETG — and one number. That row is a template default, and it is the single figure
on these sheets that gets overridden most.

**No sheet lists a 0.8 mm nozzle.** The `@0.8 nozzle` profiles exist because that's how this
printer is often run here, not because Inslogic supports it.

---

## The judgment calls

Everything else is a straight transcription of the TDS. These are not, and are the places to
look first if a print goes wrong. The PLA/PETG pair — the PETG fan and the PETG bed — has its
own section above; the three below are the ASA and TPU ones.

### 1. ASA fan is 20 %, not the TDS's 100 %

The single biggest deviation, and deliberate. **100 % part cooling on ASA warps and
delaminates parts on an open-frame MK3S+.** ASA wants heat retention; that's the whole
reason the Lack enclosure exists. The 100 % figure appears identically on **all four**
Inslogic sheets — ASA, TPU 95A, PLA Pro and PETG Pro — which settles it as a template default
rather than an ASA-specific recommendation.

Both ASA profiles instead use the Prusament ASA values — **20 % fan, off for the first
4 layers** — which is what the working `Yasin3D ASA @0.8 nozzle` profile on this machine
already runs.

TPU **does** get the full 100 %: TPU doesn't warp, so the TDS is right there.

### 2. ASA bed is 105/110 °C — outside vendor spec, on purpose

Inslogic sanctions 80–100 °C. Prusa's own ASA profile uses **105 first layer / 110 °C**.
Until 30 Aug 2026 these profiles used 100/100, the hottest the vendor allows, with a note
saying to raise it toward Prusa's numbers if parts lifted. **They now use Prusa's numbers
outright**, on the two general-purpose profiles — a hotter bed keeps the lower layers soft for
longer, so the part relieves stress instead of curling its corners up, and there is no reason
to wait for a failed print to find that out.

⚠️ **This is only safe because a glue stick goes down on this machine for every print.** ASA on
a **bare** smooth PEI sheet at 110 °C bonds hard enough to
[tear PEI off the sheet](https://forum.prusa3d.com/forum/original-prusa-i3-mk3s-mk3-how-do-i-print-this-printing-help/prusament-asa-sticking-too-well-on-pei-sheet/)
on removal — the same over-adhesion the PETG profiles here dodge by running a 70 °C bed. No
glue, no 110: drop back to 100/100.

**The two `- thin wall` profiles stay at 100/100.** They are the only print-validated ASA
profiles in this folder, the vase-mode parts they exist for have almost no cross-section to
warp, and there is nothing to gain by disturbing a known-good result.

### 3. TPU inherits `Generic FLEX`, not `Ultrafuse TPU-95A`

Worth understanding, because the existing `Ultrafuse TPU-95A - Copy` profile on this machine
is affected by it.

`Ultrafuse TPU-95A` sits at the end of this inheritance chain:

```
Ultrafuse TPU-95A → TPU-85A → TPU-64D → Ultrafuse TPC-45D → …
```

**TPC-45D is a near-rigid copolyester**, and it's where that branch's `filament_max_volumetric_speed = 15`
and `bed_temperature = 40` come from. Both get inherited all the way down to the soft 95A
profile unchanged.

Prusa's soft-TPU chain — `Generic FLEX` → `*FLEX*` — sets **1.2 mm³/s** and a **50 °C bed**
instead. That's a 12× lower flow ceiling, and the bed temperature matches Inslogic's stated
50–60 °C exactly.

So these profiles use the FLEX chain. Same reason applies at 0.8: **there is no
`Ultrafuse TPU-95A @0.8 nozzle` for the MK3 family at all** (those variants exist only for
MK4/MK4S/XL/COREONE), so `Generic FLEX @0.8 nozzle` is the only valid parent.

**Side effect worth checking:** the existing `Ultrafuse TPU-95A - Copy` profile carries that
inherited `filament_max_volumetric_speed = 15` and a 40 °C bed. For actual soft TPU on an
MK3S+ both are off — 15 mm³/s is unreachable through a Bondtech extruder with soft filament,
so in practice it means "no flow limit at all."

---

## Temperatures chosen, and why

| Profile | Nozzle | Bed | Reasoning |
|---|---|---|---|
| `Inslogic ASA` | 255 / first layer 260 | **105 / 110** | MK3S+ at 0.4 sits in the TDS's 50–100 mm/s band → 250–260 °C. Bed is Prusa's, not Inslogic's — see judgment call 2 |
| `Inslogic ASA @0.8 nozzle` | 265 / 265 | **105 / 110** | 0.8 pushes far more material/sec → the 260–280 °C band. Matches the Prusament ASA @0.8 parent, bed included |
| `Inslogic TPU 95A` | 210 / first layer 215 | 50 / 50 | MK3S+ prints TPU well under 80 mm/s → the 190–210 °C band; 210 is its top, for best layer adhesion |
| `Inslogic TPU 95A @0.8 nozzle` | 215 / 220 | 50 / 50 | Higher flow puts it at the boundary between the two bands |
| `Inslogic PLA Pro` | 205 / first layer 210 | 60 / 60 | 0.4 runs 45–80 mm/s → the 195–205 °C band; 205 is its top. The parent's 210 is above what the sheet sanctions at that speed |
| `Inslogic PLA Pro @0.8 nozzle` | 220 / 220 | 60 / 60 | ~4× the throughput → the 205–220 °C band. First layer **clamped** from the parent's 230, which the sheet never sanctions |
| `Inslogic PETG Pro` | 240 / 240 | 70 / 70 | 0.4 sits in the 230–240 °C band; the Generic PETG parent is already exactly there |
| `Inslogic PETG Pro @0.8 nozzle` | 250 / first layer 240 | 70 / 70 | ~4× throughput → the 240–255 °C band. Prusa runs the 0.8 first layer *cooler*; 240 is the slow band's top, so it stands |

Note the TPU numbers are **below** the 225 °C the Ultrafuse profile uses. Inslogic's ceiling
is 230 °C, and only at speeds this printer won't reach.

Note also how little PETG needed: **neither PETG profile overrides a temperature.** The Prusa
chain already lands on the vendor's numbers, and the only real change is the bed.

---

## Before the first print

1. **Dry the filament** — ASA 80 °C/4 h; TPU, PLA Pro and PETG Pro all 50 °C/4 h. All are
   hygroscopic; TPU especially so, and wet TPU prints badly in ways easily mistaken for a bad
   profile.
2. **TPU: fit the textured PEI sheet.** On smooth PEI, TPU can bond hard enough to damage
   the sheet on removal. PLA Pro's sheet asks for the textured sheet too, and **PETG on smooth
   PEI is the other case that damages sheets** — see Deviation 2 above.
3. **ASA: use the enclosure**, and mind the fumes — this is exactly the case the fume extractor
   project is for (`alon/homelab` → `docs/manual/fume-fan-esp32.md`).
4. **Print a temperature tower or one of the filament sample swatches** in
   `..\..\usefull\` (`ASA_filament_sample.3mf`, `TPU_filament_sample.stl`) before committing
   to a long print. Note the ASA one is a **.3mf** — it carries its own embedded config, so
   loading it will override the profile selection; re-pick the Inslogic profile after opening.
5. **Run a Live-Z check** if switching sheets — the tags in `..\..\usefull\` cover PETG at
   0.4 and 0.6.

When a profile is confirmed by a real print, replace the "UNTESTED" line in its
`filament_notes` with what was actually verified.

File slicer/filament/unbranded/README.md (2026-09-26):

# Unbranded OEM filament profiles — Prusa MK3S+

Profiles for filament that **has no manufacturer**. The folder is called `unbranded` because that
is the literal finding, not a placeholder for a brand nobody looked up.

## Why this folder exists

The repo's naming rule is *"name the grade, not the material"* — the profile name is what surfaces
a mismatch before the print does. That rule assumes a brand to name. Here there isn't one, so
**the SKU carries the identity instead**, and it goes in the filename: if a future carton arrives
with a different SKU, the mismatch shows up in the file listing rather than in a failed print.

## The profiles

| Profile | Parent | Nozzle °C | Bed °C | Fan | ₪/kg | Added |
|---|---|---|---|---|---|---|
| `PETG Basic NPETG087-ZX` | `Generic PETG` | 240 | 75 | 30–50 % | 36 | 3 Sep 2026 |
| `PETG Basic NPETG087-ZX @0.8 nozzle` | `Generic PETG @0.8 nozzle` | 240 | 75 | 30–50 % | 36 | 3 Sep 2026 |

Derived from [`Inslogic PETG Pro`](../inslogic/README.md) — same material, same `Generic PETG`
parent, same printer — with only the values this spool actually differs on changed. Deriving from a
known-complete flattened profile rather than writing one from scratch is deliberate: a hand-written
profile silently drops keys, and `inherits` is **not** resolved in user presets.

## ⚠️ PETG Basic NPETG087-ZX — read before trusting a number

**There is no brand.** Verified from the packaging, 3 Sep 2026: no manufacturer on the spool label,
none on the carton, none in the carton's parameter table. The carton is generic OEM — a printed
checklist of product lines (PLA Basic / PLA+ / PLA Pro / PLA Matte / PLA HS / PLA Rainbow / PLA Silk
/ PETG Basic / PETG HS / ABS / ASA / PA / TPU 95A) with a tick-box for whichever is inside.

```
SKU: NPETG087-ZX    Batch: B2204001W    Made in China, CE / RoHS / FCC / REACH
```

**It is not Fillamentum**, though it was described that way. Ruled out three ways:

1. Fillamentum *names* its PETG colours — Black Soul, Ghost White, Vertigo Grey — never "Basic".
2. Fillamentum publishes **235–255 °C / 65–75 °C at ±0.05 mm**; this spool says **230–260 °C /
   70–90 °C at ±0.03 mm**. Three mismatches.
3. 36 ₪/kg against a premium Czech brand selling at several times that.

### There is no TDS, and that changes the method

Every other profile in this repo is transcribed from a vendor data sheet. This vendor publishes
**none** — the product tabs are boilerplate ("store in a dry shaded place", "settings vary by
printer"). No density, no drying schedule, no mechanical data, no glass transition.

The spool label is the only real source:

| | |
|---|---|
| Printing temp | 230–260 °C |
| Bed temp | 70–90 °C |
| Diameter | 1.75 mm, ±0.03 mm *(carton)* |

**So this profile has to be settled by a calibration print, not by a document.** The numbers in it
are a defensible starting point and nothing more. `filament_notes` says so, and says
`UNTESTED` — as it should until a print has actually been run.

### ⏸️ The tower is built and DELIBERATELY not printed yet

`models/petg-temp-tower/petg-temp-tower.gcode` is sliced and ready — 2 h 41 m, 31.3 g, bands
220/230/240/250/260 baked in, base plate laid at 240 °C so adhesion is not the variable.

**Alon's decision, 3 Sep 2026: it waits for the active drybox** — a build that now lives in its own
repository.
This is a sequencing choice, not a delay to work around:

- **Calibrating on wet filament measures the water, not the temperature.** Wet PETG strings and
  bubbles at *every* band, so the print would look decisive and be wrong — and a wrong number here
  gets written into a profile and trusted for months.
- The bed-at-50 °C method documented above genuinely works, but a spool dried that way **starts
  re-absorbing as soon as it comes off the bed**. Drying into a box that then *holds* it dry is what
  makes the tower's answer reproducible rather than a one-off.

So the drybox is now on the **critical path for this profile**, which is worth knowing when
prioritising its parts.

### Drying — 50 °C for 4 h, inherited

This filament publishes **no drying schedule**. The figure used is **50 °C for 4 hours**, taken from
**Inslogic's PETG Pro TDS** — a real vendor number for the same material, which is a better basis
than the 55–65 °C ranges quoted generically online. ⚠️ It is *inherited*, not this spool's own spec.

**Do not go hotter.** PETG's glass transition is around 80 °C, but spools deform and windings **fuse
together** well below that, and a welded spool is unrecoverable. 50 °C leaves 30 °C of headroom, and
the extra drying speed from 65 °C does not pay for the risk.

**Method, with equipment already on hand:** set the printer's **heated bed to 50 °C** from the LCD,
put the spool on it, cardboard box over the top, and leave a gap so moist air can escape rather than
recirculate. The bed is thermostatically controlled, which is exactly what this needs. Then straight
into a bag with desiccant, or straight into the print.

⛔ **Not a kitchen oven** — domestic ovens cycle far outside their setpoint at low temperatures, and
an overshoot to 90 °C is how spools fuse. ⛔ **Not inside the Lack enclosure** — the Einsy board and
PSU sit in that frame, and there is no print here to justify cooking them for six hours.

*Drying fixes a wet spool; storage stops you needing to.*

### Density is an assumption

`filament_density = 1.27` is the generic figure for PETG, **not a spec**. It feeds cost-per-volume
and the filament-used estimate, so if either matters, weigh a known length and correct it.

### The bed temperature is the one number backed by a print

The label permits **90 °C**, and that is more tempting than the Inslogic case precisely because it
is *inside* vendor spec. Being inside spec changes nothing about the sheet: PETG at that
temperature bonds to a smooth PEI sheet strongly enough to **tear PEI off it on removal**.

These profiles run **75/75 °C**, 5 °C above the bottom of the label's range. That number is
measured on this printer rather than inherited: the schubox warped at 70/70, and the lid printed at
75/75 with no warping — same filament, same sheet, same large flat-bottomed geometry, so the bed
temperature is the variable that changed. It is the one setpoint in these profiles backed by a
print instead of by a data sheet; the Inslogic PETG profile settled on 70/70, and this is where the
two deliberately part company. If the first layer will not stick, raise toward 85/90 — and put
down a thin glue-stick release layer first, which is what makes the higher bed *safe* rather than
what makes it *work*.

## Cost

36 ₪/kg — at the assumed 1.27 g/cm³ that is **0.046 ₪/cm³, the cheapest filament in this repo by
volume**, about 8 % under Yasin3D PETG which previously held that position.

Sold as a 10 kg bundle, *"PETG Basic — Black & White"* — five black spools and five white.

⚠️ **10 kg of PETG is now the largest single holding in the lab, and PETG is hygroscopic.** No
drying schedule is published for it. Storage matters more than it did.

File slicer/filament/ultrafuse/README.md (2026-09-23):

# Ultrafuse (Forward AM)

## `Ultrafuse TPU-95A - Copy`

A user-modified copy of the **system** `Ultrafuse TPU-95A` preset. As with the printer preset, the
`- Copy` suffix is what PrusaSlicer names a user preset saved over a system one, so there is no user
preset of the plain name for it to duplicate — the original lives in the vendor bundle.

| | |
|---|---|
| Inherits | `Ultrafuse TPU-95A` (system) |
| Type | FLEX |
| Vendor | Forward AM |
| Keys | 85 |

**Not the same material as the Inslogic TPU presets** in `../inslogic/`, which are a different
vendor's TPU 95A and were derived from their own data sheet. Both are 95A flexibles; neither
profile's numbers transfer to the other spool.

**Status: inherited, not validated here.** This preset dates from May 2026 and no calibration print
against it is recorded in this repo. Treat its values as the vendor's starting point rather than as
something this lab has proven, and record any change with its reason — the convention the unbranded
PETG notes follow.

Versioned 23 Sep 2026; it had no master until then. Stored LF per `.gitattributes` while the live
copy is CRLF — compare with `diff --strip-trailing-cr`.

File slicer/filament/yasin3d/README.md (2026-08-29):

# Yasin3D filament profiles — Prusa MK3S+

Six PrusaSlicer profiles for **Yasin3D PLA, PETG and ASA**, at 0.4 and 0.8 nozzle.

**Read this before trusting a number in them.** Unlike the
[Inslogic profiles](../inslogic/README.md), which are transcribed from published data sheets,
**Yasin3D publishes nothing** — no TDS, no SDS, no slicer profile, no printing parameters even
on the retailer's product page. Searched 29 Aug 2026 and found nothing beyond marketing copy.

So the honest description of every one of these files is: **Prusa's generic profile for that
material, with the vendor name, price and spool weight filled in.** They are a correct starting
point, not a calibration. The temperatures, bed, fan, flow ceiling and density are Prusa's
figures for an unknown filament of that type — which is exactly what these are.

## The six profiles

| Profile | Parent | Nozzle °C | Bed °C | Fan | ₪/kg | Added |
|---|---|---|---|---|---|---|
| `Yasin3D PLA` | `Generic PLA` | 210 | 60 | 100 % | 39 ⚠️ | 29 Aug 2026 |
| `Yasin3D PLA @0.8 nozzle` | `Generic PLA @0.8 nozzle` | 220 | 60 | 100 % | 39 ⚠️ | pre-existing |
| `Yasin3D PETG` | `Generic PETG` | 240 | 85 / 90 ⚠️ | 30–50 % | 39 | 29 Aug 2026 |
| `Yasin3D PETG @0.8 nozzle` | `Generic PETG @0.8 nozzle` | 250 (first 240) | 85 / 90 ⚠️ | 30–50 % | 39 | 29 Aug 2026 |
| `Yasin3D ASA` | `Prusament ASA` | 260 | 110 | 20 % | 54 ⚠️ | 29 Aug 2026 |
| `Yasin3D ASA @0.8 nozzle` | `Prusament ASA @0.8 nozzle` | 265 | 110 | 20 % | 54 ⚠️ | pre-existing |

The 0.4-family profiles show up for any nozzle except 0.8; the `@0.8 nozzle` ones only when
the printer profile is set to 0.8. That's why each material needs two files, not one.

## The three things that are actually decisions

### 1. Prices — only PETG is a current listing

Yasin3D's Israeli seller is [filamentcenter.co.il](https://filamentcenter.co.il/). Checked
29 Aug 2026, their **entire** Yasin3D range is two products: **PETG 1 kg at ₪39** and
**ABS 1 kg at ₪49**. There is no Yasin3D PLA and no Yasin3D ASA in the catalogue.

So `filament_cost` splits two ways:

- **PETG — ₪39, verified today** against the live product page.
- **PLA ₪39 and ASA ₪54 — carried over** from the pre-existing `@0.8 nozzle` profiles, marked
  ⚠️ above. Those are historical figures of unknown date, not current prices, and they cannot
  be re-checked because the products are no longer listed.

### 2. The 0.4 profiles mirror the hand edits already in the 0.8 ones

The two pre-existing `@0.8 nozzle` profiles are not pure clones — each carries exactly one
deliberate change away from its Prusa parent, and the new 0.4 siblings reproduce it so the
pair behaves the same way at both nozzle sizes:

| Profile | Parent value | What the file uses | Mirrored into |
|---|---|---|---|
| `Yasin3D PLA @0.8 nozzle` | first layer 230 °C (print 220) | **first layer 220** — equal to print temp | `Yasin3D PLA`: first layer 210, equal to its 210 print temp |
| `Yasin3D ASA @0.8 nozzle` | first-layer bed 105 °C (bed 110) | **first-layer bed 110** — both layers at 110 | `Yasin3D ASA`: first-layer bed 110 |

Everything else in all six files is inherited, including `filament_density` — so the 1.24 /
1.27 / 1.07 figures are Prusa's generic values, never a Yasin3D measurement.

### 3. PETG inherits `Generic PETG`, not `Prusament PETG`

Not a preference. `Prusament PETG` carries `nozzle_diameter[0]!=0.6` in its compatibility
condition on top of the usual `!=0.8`, so a profile inheriting it **silently disappears from
the filament list on a 0.6 nozzle**. `Generic PETG` has no such clause. Beyond that the two
differ only in temperature and price. Same reasoning, same trap, as the
[Inslogic PETG profiles](../inslogic/README.md).

## Before the first print

1. **The PETG bed is 85 °C first layer / 90 °C, inherited.** That is hot enough for PETG to
   bond to a smooth PEI sheet strongly enough to pull PEI off it on removal. Use the textured
   sheet, or a thin glue-stick release layer, or drop the bed to 70–75 °C. The Inslogic PETG
   profiles take the last option because Inslogic's own data sheet sanctions 60–70 °C; there
   is no Yasin3D sheet to sanction anything, so the parent's value is left in place here
   rather than invented.
2. **Dry the filament.** No vendor drying spec exists; the usual figures for the material type
   apply — PLA and PETG around 50 °C, ASA around 80 °C, 4 h.
3. **ASA needs the enclosure and produces fumes worth extracting** — same conditions as the
   Inslogic ASA profiles.
4. **Run a temperature tower or a sample swatch** before committing to a long print. With no
   data sheet behind these numbers, that test *is* the data sheet.

## Building and reinstalling

These are generated, not hand-maintained. The sparse masters (`*.ini.sparse-bak`) hold only
the real overrides; [`../../../scripts/flatten_profiles.py`](../../../scripts/flatten_profiles.py)
resolves the Prusa chain and writes the complete 85-key presets, because **PrusaSlicer does
not resolve `inherits` in a user preset** — the single most important thing to know about this
folder, explained in full in the [Inslogic README](../inslogic/README.md).

```powershell
python scripts\flatten_profiles.py "Yasin3D PLA" "Yasin3D PETG"   # subset; no args = all

# then, with PrusaSlicer CLOSED (it rewrites its config folder on exit):
Copy-Item "$env:USERPROFILE\Tools\3d-printing\slicer\filament\yasin3d\*.ini" `
          "$env:APPDATA\PrusaSlicer\filament\"
```

The two pre-existing `@0.8 nozzle` files are **not** regenerated by that script and are
deliberately absent from its `JOBS` table — they are PrusaSlicer-written originals, not
flattened sparse masters, and running the script over them would rewrite them and leave a
misleading `.sparse-bak` that was never sparse.

---

**Status, 29 Aug 2026:** all six installed in `%APPDATA%\PrusaSlicer\filament\` and verified
by a real CLI slice of `3030-m3-v2.stl` — exit 0, intended temperatures in the G-code, `M900`
Linear Advance line present. **None has been print-validated**; no calibration print has been
run with any Yasin3D profile.

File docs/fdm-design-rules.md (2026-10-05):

# FDM design rules — calibrated to this printer

Generic guides quote "1.2 mm minimum wall" and "0.4 mm nozzle". Neither is the
number that matters here. What governs is the **extrusion width the slicer
actually uses**, and on the MK3S+ profiles in this repo that is **0.45 mm**, not
0.4 — read straight out of a sliced file:

```
; extrusion_width                    = 0.45
; perimeter_extrusion_width          = 0.45
; external_perimeter_extrusion_width = 0.45
; layer_height                       = 0.15
; first_layer_height                 = 0.2
```

Everything below is derived from those, so it applies to *these* profiles rather
than to FDM in the abstract.

---

## 1. The single most useful rule: quantise thin walls

A wall is built from whole perimeters. Ask for a thickness that isn't a multiple
of the extrusion width and the slicer has to either leave a void in the middle
or over-extrude to close it. **Design thin walls at multiples of 0.45 mm.**

| Perimeters | Wall | Use for |
|---:|---:|---|
| 1 | **0.45 mm** | Nothing structural. Vase mode only |
| 2 | **0.90 mm** | Absolute minimum for a non-load feature |
| 3 | **1.35 mm** | Minimum for anything that takes force |
| 4 | **1.80 mm** | Comfortable structural default |
| 5 | **2.25 mm** | Anything a screw pulls against |

The in-between values are the trap. **1.1 mm is worse than 0.90 mm** — it's two
perimeters plus a 0.2 mm gap the slicer has to fudge, so you get a void, not a
thicker wall.

Same idea vertically. `0.2 + n × 0.15` are the only heights a feature can
actually land on:

```
0.35  0.50  0.65  0.80  0.95  1.10  1.25 ...
```

A 0.8 mm lip is exactly `0.2 + 4 × 0.15` — five clean layers. A 0.75 mm lip
would land mid-layer and round to the same thing anyway, just unpredictably.

## 2. Holes print undersize

Two causes stack: the extrusion is laid on the *inside* of the arc, and each
segment cuts the chord rather than following the curve. Expect **0.1–0.3 mm**
undersize on a 0.4 nozzle.

- Grow modelled holes by ~**0.15 mm on the radius** (that's what `hole_comp`
  does in the plate model).
- Below **2 mm diameter** holes distort badly or close up. Print a pilot and
  drill.
- A horizontal hole (axis parallel to the bed) prints as an oval and needs a
  **teardrop** profile to avoid the unsupported top arc.

### Clearance between parts that have to fit together

⚠️ **There is no house default, and that is a gap rather than a decision.** Every model here picks
its own, and the two that exist do not agree:

| model | clearance | on what |
|---|---|---|
| `usbc-panel-plate` | **0.25 mm/side** | a pocket over a boss |
| `gridfinity-foot-negative` | **0** nominal, 0.1–0.25 suggested only if it seats tightly | a foot in a baseplate |

Both are values that happened to work, not measurements. The generic figure quoted online is around
0.3 mm/side; it is **not** a number from this printer and is not adopted here.

⭐ **Settle it with a test print rather than by picking one.** A clearance ladder — the same pin
through a row of holes stepping 0.05 mm — gives the answer in a single print. Record the result
**against the profile it was measured on**, exactly as §1 does for extrusion width: fit tolerance
moves with extrusion width and with material shrinkage, so a bare number with no profile attached
is the same trap §1 exists to prevent.

## 3. Overhangs — the 45° rule is not the real rule

45° is a *consequence*, not a law. The actual constraint is that **each new
extrusion must land with at least ~50 % of its width sitting on the layer
below**. Everything else follows from that:

```
max horizontal step per layer  =  0.5 x extrusion_width
overhang angle from vertical   =  atan(step / layer_height)
```

45° only pops out when `layer_height == 0.5 x extrusion_width`. That is the Cura
default for a 0.4 nozzle (0.2 mm layers, 0.4 mm width) — which is why the number
got quoted everywhere. **It is not our profile.**

Extrusion width is **0.45 mm on every profile in this repo**, 0.2 and 0.15 alike.
Layer height is what varies, and it moves the answer:

| Step per layer | Supported | @ 0.15 mm layers | @ 0.20 mm layers |
|---:|---:|---:|---:|
| 0.225 mm | 50 % | **56°** | **48°** |
| **0.20 mm** | 56 % | **53°** | **45°** |
| 0.15 mm | 67 % | 45° | 37° |

**Thin layers buy overhang.** On the 0.15 profiles the layer is a third of the
extrusion width and 53° holds; on the 0.20 profiles the same 0.2 mm step is
exactly the textbook 45°. Check which profile you're slicing with before
trusting an angle.

### The 0.2 mm step — faking a 90° overhang

A true 90° overhang (a flat ceiling) cannot be printed onto air; it must be
bridged or supported. But it can be **staircased**: break the horizontal jump
into 0.2 mm steps, one per layer, and no single layer ever overhangs more than
it can carry.

```
   abrupt 90 deg ceiling          staircased at 0.2 mm/layer
   -- must bridge --              -- prints onto itself --

   +--------------+               +--------------+
   |              |               |            __|
   |              |               |         __|
   +-----+  +-----+               |      __|
         |  |                     |   __|
         |  |                     |  |
```

The cost is height, and the exchange rate is `layer_height / step`:

| Profile | Height per 1 mm of reach |
|---|---:|
| 0.15 mm layers, 0.2 mm step | **0.75 mm** |
| 0.20 mm layers, 0.2 mm step | **1.00 mm** |

So before staircasing anything, check the depth is there — and check it against
the profile you'll actually print with. Coarser layers make a staircase cost
*more* height, not less, which is the opposite of most people's intuition.

### Holes with a horizontal axis

A round hole lying parallel to the bed is the classic 90° case: its top arc
reaches horizontal at the apex, so it droops and closes up. Three fixes, in
order of preference:

1. **Teardrop** — keep the bottom semicircle, replace the top with a point. With
   a 53° capability the apex can be steeper than the usual 45°, but 45° is the
   safe default and costs nothing.
2. **Diamond / hexagon** — same idea, easier to model, uglier bore.
3. **Sacrificial bridge layer** — let the slicer bridge one flat layer across
   the top and drill it out after. Fine when the bore finish doesn't matter.

Vertical holes (axis along Z) have none of this problem — they are just
undersized per §2.

### Bridges and orientation

- **Bridges** are fine to ~10 mm on a well-cooled machine. The slicer spans the
  **short** axis of an opening, so a 13.4 × 8.0 pocket is an 8 mm bridge, not a
  13.4 mm one.
- **Parts are weak between layers.** XY is filament-strong, Z is
  adhesion-strong-only. Orient so load runs along the layers, never across them.
- A boss standing proud is free to print. The same boss on the bed makes
  everything around it an overhang. **Orientation is a design decision, not a
  slicer setting.**

## 3b. Standing design rules

Two, and they decide most of the choices below before the geometry is drawn:

> **Prefer no support.**
> **Prefer permanent over sacrificial.**

If a design seems to need a sacrificial feature, that is usually a signal a
better design exists — not a licence to add the sacrificial feature. Snipping,
drilling and cleanup are recurring costs paid on every copy, and each one is a
chance to damage the part.

So of the techniques below, the **geometry** ones are first choice; the
**sacrificial** ones are listed to be recognised, not reached for.

## 3c. The named bridging techniques

Vocabulary, so a design conversation can point at one by name.

**Make nothing bridge** — permanent, no cleanup. Always try these first.

| Name | What it is |
|---|---|
| **Teardrop** / **diamond hole** | Horizontal-axis hole gets a pointed top instead of an arc |
| **Chamfer** / **45° taper** | A flat roof becomes a slope |
| **Arch** | A straight ceiling becomes a curve |
| **Staircase** / **stepped overhang** | The jump split into per-layer steps (§3) |

**Shorten the span** — the bridge still happens, it is just easier.

| Name | Permanent? |
|---|---|
| **Support rib** / **spar** / **intermediate wall** | ✅ permanent — first choice |
| **Sacrificial pillar** | ❌ snipped out |

**Change what the bridge lands on.**

| Name | Permanent? |
|---|---|
| **Bridge anchor** — make sure *both* ends are supported | ✅ |
| ⭐ **Two-bridge trick** | ✅ **permanent, and the one used here** |
| **Sacrificial bridge layer** — one solid layer, drilled out after | ❌ |

**Bridge vs overhang is not a distinction to blur.** A bridge has two anchored
ends and the strand is held in tension between them. An overhang is a
cantilever, held at one end only. They fail differently and the fixes differ.

### ⭐ The two-bridge trick — in three layers

The problem it solves is **a bridge with a hole in it** — a roof over a cavity
that also has an opening in it. The printer is asked to draw the hole's outline
in mid-air and produces spaghetti.

The house version runs over three layers, and the rule is **each layer does
exactly one thing**:

```
L1  THE TWO BRIDGE   slot the hole out to the cavity's FULL extent on the
                     SHORT axis. What gets laid is two strips spanning
                     wall-to-wall, each anchored at BOTH ends.

L2  THE RECTANGLE    close to a plain rectangle, SQUARE corners, hole-sized.
                     The two remaining sides bridge across onto those strips.

L3  THE CORNERS      the real rounded shape. The only new material is the
                     fillets, and they sit on the solid rectangle below.

   L1                 L2                 L3
+--+      +--+     +--+------+--+     +--+------+--+
|  |      |  |     |  |      |  |     |  /      \  |
|  |  gap |  |     |  | rect |  |     |  | hole |  |
|  |      |  |     |  |      |  |     |  \      /  |
+--+      +--+     +--+------+--+     +--+------+--+
```

**Why three and not two.** Closing straight from a rectangle to a rounded hole
lays an arc whose supporting material is only half there. Giving the curve its
own layer means no layer ever has to lay a straight run *and* a curve in the
same pass — and nothing curved is ever unsupported.

Rules that make it work:

- **Slot L1 across the short axis.** The slicer bridges the short span anyway,
  and it keeps L1 under the ~10 mm ceiling.
- **Every intermediate stage stays square.** A rounded slot puts an arc back in
  mid-air, which is the thing being removed.
- **One layer per stage**, and `layer_h` must match the slicer or the stages
  land mid-layer and get rounded away.
- **Each cut a superset of the one below**, so the larger opening wins at its
  own height and nothing depends on the order the cuts are written in.
- Costs one layer of cavity depth per stage. Check the depth is there.

Three guards are worth asserting, because each fails while the render still
succeeds and the part still looks right:

| Guard | What it catches |
|---|---|
| both spans ≤ 10 mm | sagging |
| slot taller than the hole | L1 and L2 collapse to the same shape |
| corner radius > 0 | L2 and L3 collapse to the same shape |

**Nothing is sacrificial.** All three layers are load-bearing geometry, nothing
is removed afterwards, and the sliced G-code should carry
`support_material = 0`. That is what makes this preferable to a sacrificial
bridge layer for the same problem — see §3b.

Worked example, the USB-C plate's pocket → lip:

```
L1  slot 9.6 x 8.8    -> two strips spanning 8.8 mm, anchored both ends
L2  9.6 x 3.9 square  -> the other two sides bridge 9.6 mm onto those strips
L3  r2 fillets only   -> laid on the solid rectangle below
```

Both spans under 10 mm, all three guards asserted in the model, and the sliced
G-code confirms `support_material = 0`.

## 4. Fasteners

- **Edge distance is the thing people get wrong.** Material between a screw hole
  and the part edge is a thin wall that will be *actively pulled apart* by the
  screw. Give it **3 perimeters (1.35 mm) minimum**, and prefer 1.80 mm.
- If the geometry genuinely can't afford it, an **edge-open U-slot** is stronger
  than a thin bridge — there's nothing left to split.
- Screws threading *into* plastic want a pilot around **0.8 × the thread
  diameter**, not a clearance hole. Clearance is for screws passing *through*.

Two named features, in the §3c style, so a design conversation can point at one:

- **Pinch clamp** — a slit through a boss, closed by a bolt through a captive nut, tightening a
  bore around a rod. Converts a sliding fit into a locked one without a grub screw biting into
  the rod, and it is permanent geometry rather than an added part.
- **Compliant feature** — a deliberately thinned or slotted section that flexes so two parts
  push together and stay. §3b prefers this to a sacrificial alignment aid. ⚠️ It is a flexure,
  so if it is both preloaded *and* hot, the stress-relaxation caution in
  [annealing-and-hot-service.md](annealing-and-hot-service.md) applies to it.

## 5. Corners

Round or chamfer everything you can. Sharp internal corners are stress
concentrators and crack-initiation sites; sharp external corners at the bed
amplify elephant's foot. A small chamfer on the bed face costs nothing and
fixes both.

## 5a. One profile in this repo is vase mode

`0.2mm QUALITY @MK3 - no skirt, no brim, no crossing perimeter, **lightning**`
carries `spiral_vase = 1`, `perimeters = 1`, `top_solid_layers = 0` and
`fill_density = 0%`. Slice a functional part with it and you get a single-wall
open shell — it will look plausible in preview and be useless in the hand.

The two safe 0.2 mm profiles are `0.20mm QUALITY @MK3 no skirt` and
`0.2mm QUALITY @MK3 - no skirt, no brim, no crossing perimeter` (no `lightning`
suffix). Worth grepping the sliced G-code rather than trusting the dropdown:

```sh
grep -E "^; (spiral_vase|perimeters|layer_height) " out.gcode
```

### 5b. Shapes that resist warping — round the plan view first

⚠️ **Untested here.** Reasoning plus one measured fact from this repo, not a result from this
printer.

§6 records that ASA's *small thin features lift at the corners*. The answer used to be process —
the `ASA brim + draft shield` profile, `brim_width = 5` — and **that is ruled out since 2 Oct 2026**:
never a skirt, and a part designed correctly needs no brim (Alon). So the geometry answer is the only
one, and `scripts/scad-check.sh` fails any G-code with a skirt or a brim.

- ⭐ **Round the corners as seen from above.** Lifting starts at a sharp corner in the plan view,
  where the largest contraction meets the smallest bonded area. A radius there is permanent, costs
  nothing per copy, and stays on the part.
- **Mouse ears** — small thin discs at the corners, trimmed off afterwards. ⛔ **Sacrificial, so
  §3b applies.** They are the same class of answer as a brim, which is ruled out, just with less
  cleanup. Recognise them; use the radius.
- Concentric slits cut into the underside of a large flat part are sometimes offered as stress
  relief. Not tested here, and it trades a sealed base for a slotted one — recorded for
  completeness, not recommended.

### 5c. Which way round to put text — measured here

A two-way rule. Both halves come from `models/petg-temp-tower`, which does each deliberately:

| face | do this | why |
|---|---|---|
| **Vertical** | **raise** the text | engraved text at this size *fills in* — the band numbers are embossed outward for exactly this reason |
| **Horizontal** | **engrave** it | raised text on a top face is fragile and collects stringing — the base label is engraved for exactly this reason |

Under about **5 mm digit height** the digits close up either way at a 0.4 nozzle, which is why that
model uses 6.0 mm.

## 6. Material notes for what's on the shelf

| | Warp | Bed | Watch for |
|---|---|---|---|
| **PLA** | low | 60 | Most dimensionally predictable — use it for fit tests even if the real part is ASA |
| **ASA** | **high** | 100 | Small thin features lift at the corners. Aggressive cooling splits layers — the tuned `Inslogic ASA - thin wall` profile runs 70 % fan and is single-wall only for that reason |
| **TPU** | n/a | 50 | Ignore tolerance rules; it deforms to fit. Slow retractions |

For a **fit test**, print in PLA regardless of the final material. You are
checking geometry, and PLA lies to you least.

### 6b. Choosing a material by what the part has to survive

The §6 table above ranks materials by how hard they are to *print*. This one
ranks them by how the finished part fails, using the numbers from Inslogic's own
data sheets, transcribed in
[`../slicer/reference/inslogic-filament-data.md`](../slicer/reference/inslogic-filament-data.md),
rather than folklore.

| | **PLA Pro** | **PETG Pro** | **ASA** |
|---|---|---|---|
| Tensile strength | **56.0 MPa** | 50.0 MPa | 52.4 MPa |
| Elongation at break | 20.3 % | **34.5 %** | 21.4 % |
| Flexural strength | **85.8 MPa** | 81.9 MPa | 75.2 MPa |
| Flexural modulus | **2795 MPa** | 2750 MPa | 2162 MPa |
| **Izod impact, notched** | **20.1 kJ/m²** | **4.8 kJ/m²** | 18.3 kJ/m² |
| **HDT @ 0.45 MPa** | 55.0 °C | 72 °C | **98 °C** |
| Glass transition | 65.3 °C | 65.5 °C | **108 °C** |

Two results here contradict the usual rules of thumb, and both matter:

**PLA Pro is the toughest of the three on impact — 4.2× this PETG.** "PETG is
tougher than PLA" is true of *commodity* PLA, which runs 2–5 kJ/m². PLA Pro is a
toughened grade; its own sheet claims "impact strength similar to ABS" and the
18.3 vs 20.1 against ASA bears that out. For a part whose failure mode is being
dropped, PLA Pro is the strongest thing on this shelf.

**ASA wins on heat by a mile, and that is often the real constraint.** HDT 98 °C
against PLA's 55 °C. A part left in a car in an Israeli summer sees 60–70 °C in
the cabin and more on a dashboard — PLA Pro sags there, PETG is marginal, ASA
does not care. Add UV stability and ASA is the only one of the three that
survives outdoors long-term.

⚠️ **These are ISO test bars, not printed parts.** Injection-moulded specimens
are isotropic; a printed part is much weaker across layers, typically by half or
worse. Use the table to rank materials against each other, never as an absolute
strength for a printed part. Orientation still decides more than material — see
§2.

**So, by what the part must survive:**

| The part is… | Use | Why |
|---|---|---|
| Dropped, thrown, played with, indoors | **PLA Pro** | Highest notched impact here, cheapest, easiest to print and to paint, no enclosure needed |
| Left in a car, outdoors, or in the sun | **ASA** | HDT 98 °C and UV-stable, so both the part and its paint survive. Costs an enclosure and fume handling |
| Needing to bend without snapping | **PETG** | 34.5 % elongation — it yields where the others crack. Poor on notched impact though |
| Held to a tight dimension | **PLA** | Least warp, most predictable. §6 |

⛔ **Avoid Matte PLA for anything structural.** The matting additive is a filler,
and it costs strength: measured layer adhesion on matte grades runs around **a
third** of the same maker's standard PLA, with bending strength roughly 53 MPa
against 76. It is a lovely finish for a display piece and the wrong choice for a
toy. If the appeal was that matte hides layer lines and takes primer well, five
minutes with 200-grit on PLA Pro buys the same surface and costs no strength.

**Printed parts for children — three things that are not about the plastic:**

- **Paint and primer, not just the filament.** Look for craft acrylics marked
  **EN 71-3** (European toy safety, migration of certain elements) or
  **ASTM D-4236**, and seal with a water-based varnish. Solvent enamels and
  rattle-can primers are the wrong end of this for something that gets handled
  and mouthed.
- **Layer lines hold dirt.** A sealed, painted surface is easier to clean than
  bare FDM, which is a hygiene argument for finishing rather than a cosmetic one.
- **Small parts come off.** Design for it — fillets over chamfered edges, no
  snap-off tabs, and nothing small enough to swallow on a toy for a young child.

### 6a. Joining two printed parts

The house rule mirrors §3b: prefer the permanent, structural option. For ASA and
ABS that option is a solvent weld — but it is **currently gated**, so read the
gate before the technique.

> ⛔ **ACETONE IS RULED OUT UNTIL THE FILTRATION SYSTEM IS RUNNING.**
> Alon's decision, 21 Aug 2026, restated as a condition rather than a permanent
> ban on 30 Aug. It is a decision, not a gap in anyone's information — do not
> route around it, and do not propose acetone, acetone slurry or ABS juice while
> the gate is closed. Until then, use the *Meanwhile* section below.
>
> **What the gate needs is the system running in its extract-to-outside mode.**
> Extraction is part of the planned filtration system, so this is one milestone,
> not two — but the *mode* matters, because the same hardware can run two ways:
> - **Recirculating** (Bento-style HEPA + carbon, air returned to the chamber)
>   is what handles particulates and VOCs during a print, and is what keeps the
>   chamber hot for ASA.
> - **Extracting to outside** is what solvent work needs. Vapour smoothing and
>   solvent welding release far more than a carbon tray can hold, and acetone is
>   **flammable** — lower explosive limit about 2.5 % by volume in air. Keep
>   ignition sources out of the vapour path; motors and heaters count.
>
> A recirculate-only build therefore never opens this gate.
> [chamber-sensor §8](https://github.com/AlonRR/printer-enclosure/blob/main/docs/chamber-sensor/heating-and-airflow.md) works through the airflow design that
> serves both.

**When the gate opens: ASA and ABS solvent-weld in acetone, and that beats any
adhesive.** Wet both mating faces, clamp, and the surfaces chemically fuse into a
single piece — roughly as strong as the surrounding print. Free gap filler, from
waste: dissolve failed ASA prints in acetone to a syrup, which is adhesive,
filler and colour-match at once.

**Meanwhile — what to actually use.** In rough order of joint strength:

1. **Design the joint out.** Print it as one part, or add a fastener. §3b already
   prefers permanent geometry over sacrificial; a screw into a printed boss or a
   captive nut beats every adhesive on this list and is reversible.
2. **Two-part epoxy** for anything structural. It is the closest non-solvent
   substitute for a weld: it fills gaps — which matters, because FDM mating faces
   are never truly flat — and it bonds ASA, ABS, PLA and PETG alike. Slower and
   messier than CA, and that is the trade.
3. **Cyanoacrylate for what CA is actually good at**: TPU, PLA, dissimilar
   materials, and tacking parts in place before a fastener or epoxy goes in.

**Why CA is third and not first.** It bonds only to the outer skin, so a CA joint
on an FDM part fails by **peeling the outer perimeter off the layer beneath it** —
a different failure mode from the material's own strength, at a much lower load.
It also fills no gaps. It is a positioning adhesive here, not a structural one.

**Do not mail-order cyanoacrylate.** It has a short shelf life and polymerises
in the bottle with age and heat, so slow shipping through a hot summer is the
worst case for it. Buy it locally and fresh — and buy acetone locally too, when
the gate opens, since shipping flammable solvent is a non-starter.

- [Prusa — The great guide to gluing and assembling 3D prints](https://blog.prusa3d.com/the-great-guide-to-gluing-and-assembling-3d-prints_44908/)
- [Formfutura — The ultimate 3D prints bonding guide](https://www.formfutura.com/blog/blogs-1/the-ultimate-3d-prints-bonding-guide-50)

---

## Applied: the USB-C panel plate

Audit of [`models/usbc-panel-plate/`](../models/usbc-panel-plate/), against §1
and §4. The `.scad` echoes all of these on every render — and, since the review
of 18 Aug 2026, computes them from the **as-cut** dimensions rather than the
nominal ones.

| Feature | As cut | Perimeters | Verdict |
|---|---:|---:|---|
| `web above/below` | 5.60 mm | 12.4 | ✅ |
| `outboard of screw` | 2.70 mm | 6.0 | ✅ |
| `frame beside port` | 2.55 mm | 5.7 | ✅ |
| `web beside pocket` | 1.20 mm | 2.7 | ⚠️ between 2 and 3 perimeters |
| `frame over/under` | 1.10 mm | 2.4 | ⚠️ same |
| `prot -> screw` | 0.95 mm | 2.1 | ⚠️ same |
| `lap left at notch` | 0.55 mm | — | ⚠️ thin, but it is lap not structure |
| `lip_t` | 0.80 mm | 4 layers | ✅ whole layers at 0.2 mm |

### The trap this section exists to record

`outboard of screw` used to read **0.55 mm** here and was graded a failure. It
was worse than that: the echo computed `(plate_w - screw_span - screw_d) / 2`
from the *nominal* hole, while the cut was grown by `hole_comp`. The real figure
was **0.40 mm** — under a single extrusion.

> **A diagnostic that measures something adjacent to what it claims is worse
> than no diagnostic.** It had been quoted a dozen times as evidence the part
> was merely marginal.

Every echo and assert in that model now derives from as-cut names defined once
at file scope. The fix was not the arithmetic; it was removing the *opportunity*
for the audited number and the built geometry to disagree.

### Why the staircase was abandoned

Printed back-face-down, the step from the rear pocket to the lip is a flat 90°
ceiling. §3's staircase would need `reach × (layer_h / step)` of depth:

```
horizontal reach : 2.25 mm   (Y governs, measured from the ledge edge)
depth available  : 1.20 mm   (plate_t 2.4 - lip_t 0.8 - two ledges 0.4)

@ 0.20 mm layers : needs 2.25 mm  -> DOES NOT FIT, short by 1.05 mm
```

It fitted by 0.05 mm at 0.15 mm layers and stopped fitting the moment the
profile moved to 0.20 — the geometry never changed. That is the whole reason the
exchange-rate table above is keyed by layer height.

What the model does instead is **two ledges, one layer each**: a rounded step
matching the lip profile, then two relief lines. Together they cost 0.4 mm of
pocket depth. The remaining reach is made in one jump, which is fine — a bridge
of this span is well within the machine, on a face hidden against the connector.

---

## Claims deliberately NOT imported

A design-tips poster (in Sources) was compared tip by tip against this document. Most of its advice
is already here and more precisely, because these numbers come from this printer's own sliced
output. Three of its claims **conflict** with what this machine does, and are recorded so nobody
imports them later by accident:

| the poster says | this repo measures | why they differ |
|---|---|---|
| wall steps 0.8 / 1.2 / 1.6 mm | **0.90 / 1.35 / 1.80** | it assumes a 0.4 mm extrusion width; §1 uses the width the slicer actually emits, **0.45** |
| bridges of "2 cm+" | **~10 mm** | asserted in `usbc-panel-plate.scad` against the ceiling this machine was measured at |
| engrave text into vertical faces | **raise** it on vertical faces | §5c — engraved text at readable sizes fills in here |

⭐ **The pattern is worth more than the three corrections.** Every conflict is a generic figure
meeting a measured one, and in each case the generic figure is not wrong in general — it is wrong
*for this extrusion width, this cooling, this nozzle*. That is the same reason §1 tells you to read
the width out of the profile instead of trusting a table.

## Sources

- [Protolabs Network — How to design parts for FDM 3D printing](https://www.hubs.com/knowledge-base/how-design-parts-fdm-3d-printing/)
- [Layer X — FDM design rules: wall thickness, overhangs, bridging, tolerances](https://layerx3d.in/blog/fdm-design-rules-wall-thickness-overhangs-bridging-tolerances)
- [SGD3D — FDM 3D printing design guide: strength & accuracy](https://sgd3d.co.uk/3d-printing/fdm-3d-printing-design-guide/)
- [Mandarin3D — Wall thickness guide](https://mandarin3d.com/blog/wall-thickness-guide-minimum-and-optimal-measurements)
- [Simple Machining — DFM for 3D printing](https://www.simplemachining.com/blogs/dfm-for-3d-printing-a-practical-design-guide)
- Billie Ruben, *CAD Design Tips for 3D Printing* — [infographic poster](https://imgur.com/gallery/i-made-another-infographic-poster-3d-printing-SqIdFwB). Someone else's work, so linked rather than reproduced. Compared tip by tip against this document; see *Claims deliberately NOT imported* above.

The extrusion-width, layer-height and bridge figures are read from this repo's
own sliced output, not from those pages.

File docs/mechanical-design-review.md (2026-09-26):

# Mechanical design review — the questions a collision check never asks

A reference for reviewing a printed mechanical assembly in this repo, and a checklist to run against an
OpenSCAD model. Written 26 Sep 2026, after the desiccant module's spring inserts fell over in the first
coupon. The review that followed is what this page came out of.
It found four ceilings that cannot print, a joint with no seal, and a spring whose preload is smaller
than its tolerance. The checks had called all of them fine.

Printing rules (quantised walls, holes, overhang angles, bridging tricks, materials) are in
[fdm-design-rules](fdm-design-rules.md) and are not repeated here. This page is about the assembly.

**Tags.**
- **[standard]** a code or standard.
- **[handbook]** a textbook, handbook or paper.
- **[vendor]** a maker's own guide or datasheet.
- **[community]** blogs, wikis, trade press.
- **[inferred]** reasoning or arithmetic done here.

`S#` refers to the source list at the end.

`§5.x` refers to a numbered finding in the desiccant module's own facts document. That build moved to
its own repository in September 2026 and is not public, so those sections cannot be opened from here;
the citation is kept only to mark where a claim came from. Every claim below is stated in full, so
nothing depends on following one.

---

## 0. The pattern

Every check in the desiccant model asked one question: **does the part exist here without colliding?**
Each miss was a different question:

| The question that was not asked | The miss |
|---|---|
| Does air actually get through? | two broken air paths (§5.12, §5.14) |
| What does gravity do when it is mounted? | the cartridge bypass, the hanging gates (§5.15, §5.17) |
| Can it be put in at all? | a gate slot closed at both ends (§5.17) |
| Does it stay where it was put? | the spring insert (§5.22) |
| Does its first layer hang off one edge? | four valve ceilings (§5.23) |

A part does not live in one state. It lives through a set of them, and **every check should say which
set it covers**:

| Code | The set |
|---|---|
| **O** | every orientation gravity can take: on the bench, flipped to screw, hung on the wall |
| **A** | every step of assembly *and* disassembly |
| **T** | both tolerance extremes, not nominal |
| **H** | hot, at the service temperature |
| **R** | after creep, relaxation and compression set |
| **M** | the whole range of motion, not a few poses |
| **S** | service: taken apart and refitted, repeatedly |

## 1. Assembly — located before released

- **Boothroyd–Dewhurst's rule: "design so that a part is located before it is released."** A part that
  has to be held until something else arrives is, in their scoring, *holding down required*: the costly
  case. [handbook S1] The spring insert broke exactly this.
- **Justify every separate part.** It must move relative to the others, be a different material, or be
  separate so the others can be assembled. A small elastic motion is not a reason, because a flexure can
  provide it. [handbook S1] Here the insert is separate for a real reason: so it can be annealed and
  reprinted without the 190 g valve (§5.18). The cost of that choice is retention, which must then be
  designed in.
- **Symmetric about the insertion axis, or obviously not.** Poka-yoke features reject the wrong way
  round by shape. [handbook S1; community S21] Check each part rotated 180° about each axis:
  - the wrong pose must collide with its seat;
  - the collision must also be **bigger than the part's own compliance**. An upside-down spring
    insert collides with the body by 1.3 mm, but its fingers bend 1.4 mm, so the body still closes
    (§5.23). [inferred]
- **Assemble from above, around one axis, with lead-ins.** Access must be clear and visible.
  [handbook S1]

## 2. Constraint — every contact needs a force that keeps it closed

- A rigid body has six degrees of freedom. **A contact is a constraint only while a nesting force keeps
  it closed**: gravity, a spring, a cam. That force has to exist in every state of the machine.
  [community S2, after Blanding]
- **Gravity nests in one orientation only.** A pocket that seats a part on the bench may hold nothing
  once the module hangs on the wall, or while the part beside it is out for service. Every loose part
  needs a named retaining force, for each state in O and A. [inferred]
- **Over-constraint turns tolerance into stress or binding.** Pick one datum and give the others
  clearance. [community S2] The gates here do it right: sprung onto the floor, with clearance in the
  dovetail.

## 3. Tolerance — compliance must be large against the stack

- **Worst case, not RSS, for prints.** RSS assumes independent, centred, normal contributors. FDM errors
  are largely systematic:
  - the same printer and spool;
  - holes always undersize;
  - the first layer always spread;
  - one shrink in XY and another in Z.

  So check the worst case, and treat RSS as the optimistic bound. [community S3; inferred]
- **Starting numbers** are about ±0.2 mm on a calibrated desktop machine; calibrate with a printed
  ladder. [community S27] Elephant's-foot compensation is ~0.2 mm, and this repo's profiles set it.
  [vendor S5]
- ⭐ **A spring's or seal's working deflection must be several times the worst-case stack**, because
  force and squeeze are proportional to deflection. Aim for at least 3×. [inferred]
  - *The desiccant spring:* 0.7 mm preload against a ±0.23 mm RSS stack (±0.5 worst case), and it needs
    0.667 mm hot (§5.23).
  - *A 0.2 mm gasket squeeze is one layer.* A ±0.1 mm stack gives 12–38 % squeeze; ±0.2 mm gives 0–50 %.
- **The remedy is a softer element with more travel,** not a stiffer one. A tip-loaded cantilever's root
  strain is ε ≈ 1.5·t·y/L², so a longer, thinner finger takes more deflection at the same strain and
  force. [vendor S8; inferred]
- **Where a thin dimension is set matters.** A finger printed flat is quantised to layers (0.8 or
  1.0 mm), and its force goes as t³. The desiccant insert prints on its back, which puts the 0.9 mm into
  the bed plane: two perimeters, set by the extrusion width instead. [inferred]

## 4. Printed plastic under load

- **Interlayer strength is about a quarter of in-plane.** Printed ASA gives 11 MPa across layers
  against 42 MPa along them. [vendor S6] Load along the roads, never across them, and make springs bend
  in the print's plane. [vendor S4]
- **Moulded ASA shrinks 0.5–0.9 %.** [vendor S7] A fit between a dimension printed in XY and one printed
  in Z inherits the difference. This repo's profile compensates neither (0 %).
- **Sealing faces as top or bottom skins, never as layered side walls.** Rib large flat faces against
  warp. [inferred]

## 5. Fastening into printed parts

- **Plastic under a screw head creeps, and the joint loosens**, faster the hotter it is. [vendor S9] A
  **compression limiter** (a metal sleeve as long as the plastic) or a hard stop carries the clamp load
  instead. [vendor S11] Pan heads with washers, not countersunk heads, which put the hole into hoop
  tension. Keep the edge distance at least max(d, 2t). [vendor S9]
- **Self-tapping into plastic:**
  - pilot ~0.8–0.9 d, boss OD ~2 d, engagement ≥ 2 d (EJOT, Covestro; both for moulded bosses);
  - tighten to ≥1.2× driving torque and ≤0.5× stripping torque;
  - on refitting, find the existing thread. [vendor S9, S10]

  Printed pilots come out undersize, so size them from a coupon. [inferred]
- **Nuts and inserts, M3 pull-out in PETG** (CNC Kitchen):
  - bottom-inserted nut ≈ 1.63 kN;
  - heat-set insert ≈ 1.17 kN;
  - screwed direct ≈ 1.16 kN;
  - **side-slit nut ≈ 0.84 kN.**

  Heat-set inserts take about three times the torque of a printed thread, and are the choice for joints
  opened repeatedly. [community S12]
- **A nut in a side slit is held by nothing once its screw is out** — the §0 bug again. It needs its own
  retention, or an assembly order that never tilts it out. [inferred]
- **Set screws in printed bosses: no source found.**
  - The screw's reaction sits on plastic threads that creep hot.
  - A set screw on a round shaft slips.
  - File a flat where it bears, and back the thread with a metal nut or insert, or use a split clamp.
    [inferred]

## 6. Seals and gaskets

- **Squeeze targets:**
  - Parker face seals run ~18–27 %, and permanent set is lowest at 25–30 %. [vendor S13]
  - Solid silicone runs 15–25 %. [vendor S14]
  - Size the *minimum* squeeze with every tolerance at its limit. [vendor S13]
- **Geometry, not torque.** A hard compression stop fixes the squeeze whatever the screws do. [community
  S15] The desiccant module's base seal does this since 26 Sep: the body's walls land on the plate as the
  stop, and a hollow TPU bead beside them takes the squeeze (facts §5.24). The valve-to-body joint has
  the same since then: a hollow ring in a groove, with the faces still meeting (facts §5.25).
- **Give it volume.** Elastomer is incompressible and bulges into its groove. [vendor S14]
- **TPU takes a set.** Elastollan 95A shows about **30 % at 23 °C over 72 h and 45 % at 70 °C over 24 h**
  (moulded, ISO 815). [vendor S16] A 0.2 mm squeeze in the hot path can lose ~0.09 mm early. So hot
  seals want more squeeze behind a hard stop, and should be replaceable. [inferred]
- **Every interface between two pressures needs a seal, or a stated reason why not.** A leak through a
  flat gap goes as the cube of the gap, so it is decided by how flat the faces print. [inferred]
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

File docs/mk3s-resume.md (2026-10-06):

# Resuming a print the printer stopped — with the part still on the bed

**Written 15–16 Sep 2026**, during a real recovery: a 21 h PETG print stopped by **MINTEMP BED**
after 11 h 51 m, at about **10.3 mm** of 58.6 mm. The part stayed stuck to the sheet, so the job was
worth resuming rather than restarting.
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

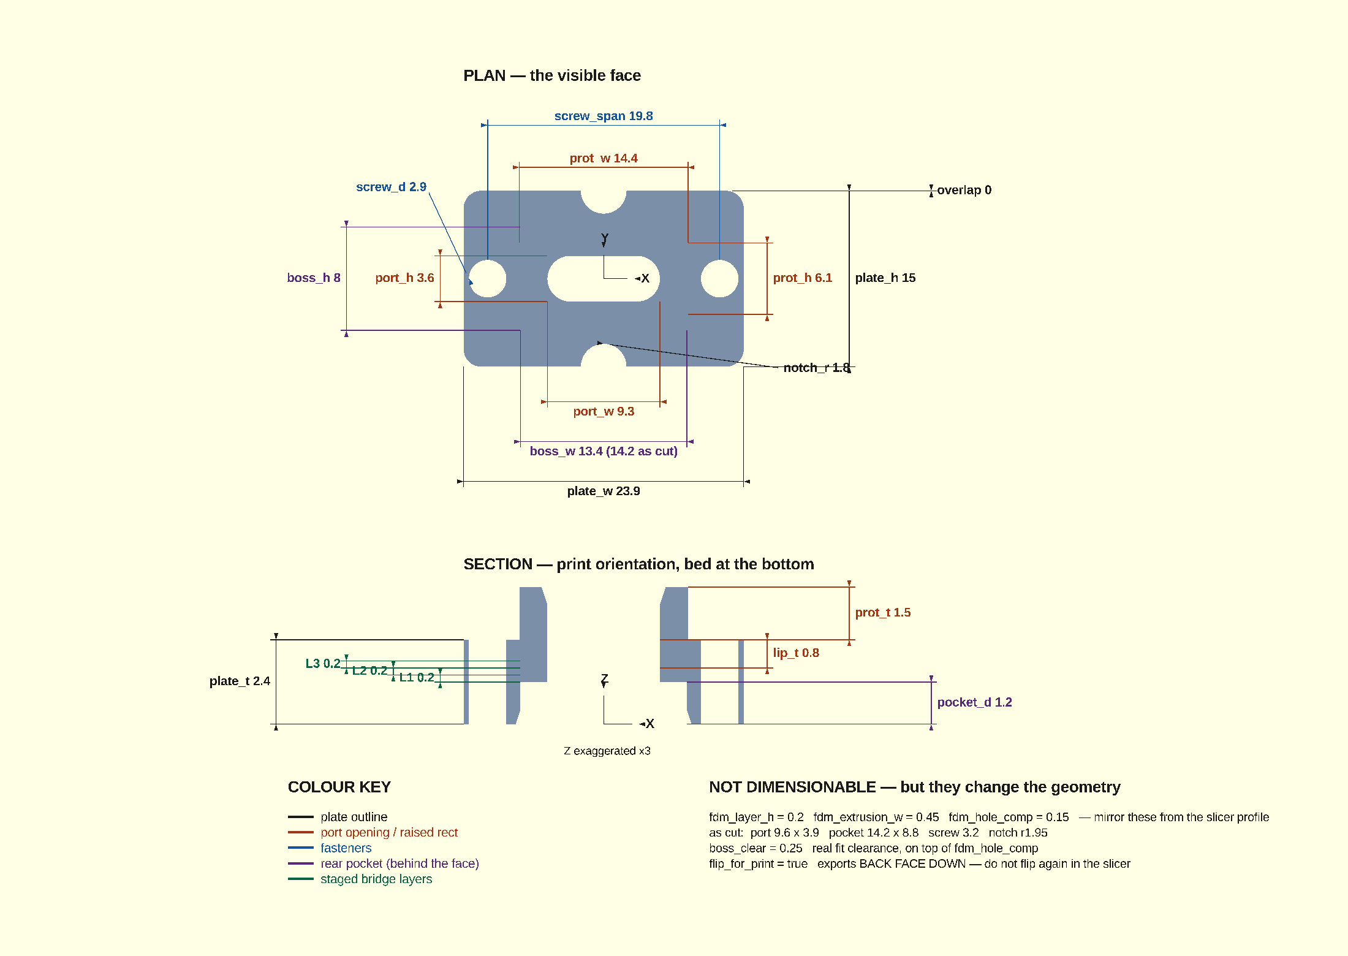
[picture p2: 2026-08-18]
models/usbc-panel-plate/parameter-map.png

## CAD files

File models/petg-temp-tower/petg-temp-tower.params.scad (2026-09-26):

// SPDX-FileCopyrightText: 2026 Alon A. Rabinowitz
// SPDX-License-Identifier: CC-BY-4.0
// Shared under the Creative Commons Attribution 4.0 International licence
// (LICENSES/CC-BY-4.0.txt): reuse freely, including commercially, with attribution.

/*
Everything you SET for the PETG temperature tower. Render petg-temp-tower.scad, not this file.

The tower exists because the new unbranded PETG (SKU NPETG087-ZX) ships with NO data sheet - the spool label gives a 30 C nozzle band and nothing else. A 30 C band is far too wide to pick a number out of, so the number has to be measured.
*/

/* [The band temperatures — what is actually being tested] */
/*
One band per temperature, printed bottom to top. These span the label's full 230-260 C range, because the whole point is that no narrower claim exists to trust.

The slicer is what changes the temperature; the model only makes each band identifiable and gives it features that fail visibly. Add an M104 at each band boundary via the layer slider - petg-temp-tower.scad echoes the exact Z heights and layer numbers to use.
*/
temps = [220, 230, 240, 250, 260];

/*
220 IS DELIBERATELY BELOW THE LABEL, which claims 230-260. The label is an
unbranded OEM's generic claim with no data sheet behind it, and a documented
Polymaker PETG turned out to print best at 220 - ten degrees under its own
manufacturer's stated range. One extra band is cheap; discovering afterwards
that the optimum sat below the range you tested is not.
*/

/* [Band geometry] */
band_h  = 10.0;     /* Height of each band. MUST be a whole number of layers or the temperature change lands mid-band and the boundary stops being readable — the .scad asserts this against fdm_layer_h. */
body_w  = 30.0;     /* Across the front face. Wide enough for three digits at text_size without crowding the corners. */
body_d  = 18.0;     /* Front to back. Also the bridge span, so this is the number that decides how hard the bridge is. */

/* [Features that fail visibly — one per failure mode] */
/*
Each band carries the same three features, so the ONLY variable between bands is temperature. That is the entire experimental design: vary one thing.
*/
shelf_len   = 7.0;      /* How far the shelf sticks out with nothing under it. A 90 degree overhang, deliberately the hardest case rather than a 45 degree one — too hot and it droops, and droop is easy to see against the band above. Sits on the BACK face: an earlier version put it on the +X face and mirrored the second tower, which pointed BOTH shelves into the valley and cut the travel gap from 40 mm to 33. */
shelf_t     = 2.0;      /* Thickness of the shelf. Thin enough to sag if it is going to, thick enough to survive handling. */
shelf_z     = 0.55;     /* Where the shelf sits within its band, 0..1. Above middle for the same settling reason as the bridge, and with clean air below it so droop is visible. */

bridge_w    = 8.0;      /* Depth of the bridge bar, in Y. Wide enough to judge sag along its length, narrow enough that it does not shade the towers from the fan. */
bridge_t    = 1.2;      /* Thickness, six layers. A bridge this thin sags visibly when too hot; a thick one just prints. */
bridge_z    = 0.78;     /* Where the bridge sits within its band, 0..1. HIGH, near the top, and that is the important part.

M104 does not wait. At each band boundary the new temperature is commanded and printing continues immediately, so the first layers of a band are still being fed plastic that was melted at the PREVIOUS temperature - the melt zone holds roughly a layer or two of it. A bridge at the bottom of a section is therefore a blend of two temperatures and cannot be attributed to either. Near the top, the band has long settled and the bridge tests the temperature its label claims. */

fin_w       = 1.2;      /* A thin vertical fin on the back. Narrow features are where stringing and over-extrusion show first. */
fin_len     = 4.0;      /* How far it stands off the back face. */

/* [Labels] */
text_size   = 6.0;      /* Digit height. Under about 5 mm the digits close up at 0.4 mm nozzle and stop being readable, which defeats the point of labelling. */
text_depth  = 0.6;      /* Embossed OUTWARD, not engraved. Raised text prints cleanly on a vertical face; engraved text at this size fills in. */

/* [Stringing — the fourth failure mode] */
/*
TWO towers, not one, and the gap between them is the test. A single tower never travels far, so retraction is barely exercised and stringing does not show. Printing a pair forces a long travel move at every layer of every band, which is exactly when PETG strings - and PETG strings more readily than any other common material.

Added after checking what established temperature towers include: overhang, bridge, thin wall AND retraction. The first three were already here; this is the one that was missing.
*/
twin        = true;     /* Print the pair. Set false for a single tower if bed space is tight. */
base_t      = 1.0;      /* A thin plate joining the two towers. Three purposes, all real: it makes the model ONE part rather than two, which is what scad-check.sh wants and what stops a deliberate pair being indistinguishable from an accidentally fragmented model; it puts a wide first layer on the bed, which is itself a bed-adhesion test at 70 C - an open question for this filament; and it stops a tall thin tower being knocked over by a travel move. Must be a whole number of layers. */
tower_gap   = 40.0;     /* Clear air between the two towers. Long enough that a string spans it visibly rather than being dragged back into the wall. */

/* [Identity — what filament this tower actually tested] */
/*
A finished temperature tower is a physical record, and an unlabelled one is worthless the moment a second spool enters the room: the bands say 230/240/250/260 but nothing says WHAT was printed at those temperatures. Engraved into the base so it survives being handled, and so it cannot be confused with the band labels.

ENGRAVED, not embossed, unlike the band numbers. The base's top face is a horizontal surface, where raised text is fragile and collects strings; recessed text on a flat top prints cleanly and stays readable.
*/
label_line1 = "PETG";              /* The material. */
label_line2 = "NPETG087-ZX";       /* The SKU, which for this filament IS the name - there is no brand. */
label_size  = 4.5;                 /* Small enough for two lines to fit between the towers, large enough to read at 0.4 mm nozzle. */
label_depth = 0.4;                 /* Two layers deep, leaving three layers of base under it. */

/* [Modelling] */
weld = 0.5;         /* How far each feature is buried INTO the body. Features that merely touch a face are not fused - CGAL reports them as separate volumes and the STL is multi-part, which scad-check.sh blocks. Coincident faces are a modelling bug, not a style choice. */

/* [Print reality — cross-checked by scripts/scad-check.sh against the profile used] */
fdm_layer_h     = 0.2;      /* Must match the print profile. band_h has to be a whole multiple of this. */
fdm_extrusion_w = 0.45;     /* 0.4 nozzle. Feeds the thin-feature check on fin_w. */

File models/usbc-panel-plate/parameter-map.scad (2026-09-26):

// SPDX-FileCopyrightText: 2026 Alon A. Rabinowitz
// SPDX-License-Identifier: CC-BY-4.0
// Shared under the Creative Commons Attribution 4.0 International licence
// (LICENSES/CC-BY-4.0.txt): reuse freely, including commercially, with attribution.

/*
Parameter map for usbc-panel-plate.scad

A DIMENSIONED drawing, not a callout drawing. Every measurement is shown as a proper dimension line — extension lines out to the feature, arrowheads at both ends, the parameter name and its live value on the line — so it is never ambiguous WHAT is being measured, or BETWEEN WHICH TWO EDGES.

A numbered dot can only say "this feature"; a dimension line says "this distance, from here to here". That is why every measurable span here gets a dimension line, and a leader is used only for the two things that are genuinely features rather than spans.

Colour groups the measurements by what they belong to, and the key is bottom left.

Prior art: Don Smiley's OpenSCAD dimensioned-drawings library has exactly these modules — dimensions, leader_line, arrow, titleblock — but it is unmaintained and depends on a font from Thingiverse that predates native text(). BOSL2 offers stroke() with arrowheads, which is the primitive rather than the system. Conventions taken from both, implemented natively so this file has no dependencies.

The point is that it cannot drift: it INCLUDES the model rather than restating it, so every outline and every number is whatever the model currently says. Edit a parameter, re-render, and the map is correct again.

    openscad -o parameter-map.png --imgsize=2200,1560 \
      --camera=6,-17,0,0,0,0,205 --projection=ortho parameter-map.scad

draw_model = false MUST come after the include — in OpenSCAD the last assignment in a scope wins, so this suppresses the part while keeping all of its variables.
*/

include <usbc-panel-plate.scad>
draw_model = false;

include <draw2d.scad>

/* Where the two views sit, and the Z exaggeration on the section. */
sec_y = -60.0;
zs    = 3.0;

/* ===== PLAN ================================================================ */
/*
Dimensions sit on a LADDER — each one gets its own offset from the part, so none can land on another. Innermost measurements go closest; the overall outline goes furthest out. That ordering is the drafting convention and it is also what keeps this readable as parameters get added.
*/
color(C_PART) projection() usbc_panel_plate();
heading("PLAN — the visible face", [-plate_w / 2, plate_h / 2 + 9.4]);

/* --- above (rungs at +12.0, +15.4) */
dim_h(-prot_w / 2, prot_w / 2, plate_h / 2 + 2.0, prot_h / 2,
      str("prot_w ", prot_w), C_PORT);
dim_h(-screw_span / 2, screw_span / 2, plate_h / 2 + 5.6, sd / 2,
      str("screw_span ", screw_span), C_FIX);

/* --- below (rungs at -13.0, -16.4, -19.8) */
dim_h(-pw / 2, pw / 2, -plate_h / 2 - 3.0, -ph / 2,
      str("port_w ", port_w), C_PORT, false);
dim_h(-bw / 2, bw / 2, -plate_h / 2 - 6.4, -bh / 2,
      str("boss_w ", boss_w, " (", bw, " as cut)"), C_POCK, false);
dim_h(-plate_w / 2, plate_w / 2, -plate_h / 2 - 9.8, -plate_h / 2,
      str("plate_w ", plate_w), C_OUT, false);

/* --- right (rungs at +16.2, +20.4, +25.2) */
dim_v(-prot_h / 2, prot_h / 2, plate_w / 2 + 2.0, prot_w / 2,
      str("prot_h ", prot_h), C_PORT);
dim_v(-plate_h / 2, plate_h / 2, plate_w / 2 + 9.0, plate_w / 2,
      str("plate_h ", plate_h), C_OUT);
dim_v(gap_h / 2, plate_h / 2, plate_w / 2 + 16.0, plate_w / 2 - 1.0,
      str("overlap ", overlap), C_OUT);

/* --- left (rungs at -16.2, -21.0) */
dim_v(-ph / 2, ph / 2, -plate_w / 2 - 2.0, -pw / 2,
      str("port_h ", port_h), C_PORT, false);
dim_v(-bh / 2, bh / 2, -plate_w / 2 - 10.0, -bw / 2,
      str("boss_h ", boss_h), C_POCK, false);

/* features rather than spans */
leader([-plate_w / 2 - 3.0, 7.4], [-screw_span / 2 - sd / 2, 0],
       str("screw_d ", screw_d), C_FIX);
leader([plate_w / 2 + 3.0, -7.6], [notch_x, -plate_h / 2 + nr],
       str("notch_r ", notch_r), C_OUT);

translate([0, 0]) { axis("X", 0, 2.6, C_OUT); axis("Y", 90, 2.6, C_OUT); }

/* ===== SECTION ============================================================= */
translate([0, sec_y]) {
    heading("SECTION — print orientation, bed at the bottom", [-plate_w / 2, zs * 4.4]);
    /*
    Section the PRINT-ORIENTED assembly, not the raw module. usbc_panel_plate() is authored front-at-z-0 with the protrusion at NEGATIVE z, so sectioning it directly draws the protrusion below the plate — design orientation, under a heading that says print orientation. Applying the same flip the export does puts the bed at y = 0 and everything above it, which is what the dimensions below already assume.
    */
    scale([1, zs]) color(C_PART)
        projection(cut = true) rotate([-90, 0, 0])
            translate([0, 0, top_z]) rotate([180, 0, 0]) usbc_panel_plate();

    /* right ladder */
    dim_v(zs * (plate_t - lip_t), zs * plate_t, plate_w / 2 + 2.0, pw / 2,
          str("lip_t ", lip_t), C_PORT);
    dim_v(zs * plate_t, zs * (plate_t + prot_t), plate_w / 2 + 9.0, prot_w / 2,
          str("prot_t ", prot_t), C_PORT);
    dim_v(0, zs * pocket_d, plate_w / 2 + 16.0, bw / 2,
          str("pocket_d ", pocket_d), C_POCK);

    /*
    left ladder — plate_t furthest out, the three staged layers stepping in. They are the reason the section is exaggerated at all: at true scale three 0.2 mm layers are one pixel.
    */
    dim_v(0, zs * plate_t, -plate_w / 2 - 16.0, -plate_w / 2,
          str("plate_t ", plate_t), C_OUT, false);
    for (i = [0 : 2]) {
        zlo = zs * (pocket_d + i * fdm_layer_h);
        nm  = ["L1", "L2", "L3"][i]; /* spelled out in the key */
        dim_v(zlo, zlo + zs * fdm_layer_h, -plate_w / 2 - 2.0 - i * 4.0,
              -bw / 2, str(nm, " ", fdm_layer_h), C_STAGE, false);
    }

    axis("X", 0, 3.0, C_OUT);
    axis("Z", 90, 3.0, C_OUT);
    color(C_OUT) translate([-3.4, -2.6])
        text(str("Z exaggerated x", zs), size = txt * 0.9);
}

/* ===== KEY ================================================================= */
translate([-plate_w / 2 - 15.0, sec_y - 8.0]) {
    heading("COLOUR KEY", [0, 2.2]);
    keys = [[C_OUT, "plate outline"], [C_PORT, "port opening / raised rect"],
            [C_FIX, "fasteners"], [C_POCK, "rear pocket (behind the face)"],
            [C_STAGE, "staged bridge layers"]];
    for (i = [0 : len(keys) - 1])
        translate([0, -i * txt * 1.7]) {
            color(keys[i][0]) square([2.2, lw * 3]);
            color(keys[i][0]) translate([2.8, -txt * 0.34])
                text(keys[i][1], size = txt);
        }
}

/* Facts with no place on a drawing. */
translate([9.0, sec_y - 8.0]) {
    heading("NOT DIMENSIONABLE — but they change the geometry", [0, 2.2]);
    notes = [
        str("fdm_layer_h = ", fdm_layer_h, "   fdm_extrusion_w = ",
            fdm_extrusion_w, "   fdm_hole_comp = ", fdm_hole_comp,
            "   — mirror these from the slicer profile"),
        str("as cut:  port ", pw, " x ", ph, "   pocket ", bw, " x ", bh,
            "   screw ", sd, "   notch r", nr),
        str("boss_clear = ", boss_clear,
            "   real fit clearance, on top of fdm_hole_comp"),
        str("flip_for_print = ", flip_for_print ? "true" : "false",
            "   exports BACK FACE DOWN — do not flip again in the slicer")
    ];
    for (i = [0 : len(notes) - 1])
        color(C_OUT) translate([0, -i * txt * 1.7 - txt * 0.34])
            text(notes[i], size = txt * 0.95);
}

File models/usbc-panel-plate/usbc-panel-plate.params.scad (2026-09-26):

// SPDX-FileCopyrightText: 2026 Alon A. Rabinowitz
// SPDX-License-Identifier: CC-BY-4.0
// Shared under the Creative Commons Attribution 4.0 International licence
// (LICENSES/CC-BY-4.0.txt): reuse freely, including commercially, with attribution.

/*
usbc-panel-plate.params.scad — THE HEADER

Every value you SET lives here and nowhere else. This file contains no geometry, no modules and no derived values: nothing here is computed from anything else, so any line can be changed without reading the rest.

The geometry, the derived values, the echoes and the guards are in usbc-panel-plate.scad, which includes this. Render THAT file, not this one — on its own it produces nothing.

Tags to keep honest as you edit:
    MEASURED      taken off the real part with calipers
    <<CONFIRM>>   scaled off a photo, NOT measured, and still feeding the fit

Comment style: prose is written as one long line per paragraph inside a block comment, so it reflows to whatever width the editor is at. Hard-wrapped double-slash blocks go ragged the moment the window changes size. The bracketed section markers below are OpenSCAD Customizer syntax and must stay on their own single line.

One trap worth knowing, since this file is mostly block comments: OpenSCAD does not nest them. Writing a close-comment token inside prose ends the comment there, and the rest of the paragraph is parsed as code.
*/

/* [The opening in the case panel — what the plate has to cover] */
gap_w   = 23.4;     /* MEASURED. Width of the opening. */
gap_h   = 15.0;     /* MEASURED. Height of the opening. */
panel_t = 0.6;      /* MEASURED. Sheet thickness of the case panel. */
overlap = 0;        /* How far the plate laps onto the panel, all the way round. The screws pass through open air, so this lap is the ONLY thing retaining the plate. Hard floor: corner_r * (1 - 1/sqrt(2)) — below that the rounded corners fall INSIDE the aperture and leave four open gaps into the case even though every straight edge "covers". */

/* [Plate outline] */
/*
plate_w is whichever of two floors is higher.

COVERAGE is gap_w + 2*overlap. Below this the plate does not span the aperture. This one is physics — there is no way around it.

FASTENERS is the screw envelope plus material outboard of each hole. This one is a CHOICE, and it is usually the binding constraint: at overlap 0.5, coverage wants 24.4 and the fasteners want 25.7.

To make the plate narrower, lower the fastener floor — either by trimming screw_edge_margin, or by switching to edge-open slots, which removes the floor altogether because there is no bridge of material left to split.
*/
screw_envelope = 22.70;     /* MEASURED, outer edge to outer edge. */
screw_style = "hole";       /* "hole" = closed clearance hole, needs material all the way round, and the edge distance is structural. "slot" = U-shaped and open to the plate edge, so the plate slides onto the screws — nothing is left to split, the fastener floor disappears, and the plate can shrink to the coverage floor. */
screw_edge_margin = 0.6;      /* Material outboard of each hole, per side. Ignored when screw_style = "slot". Three perimeters is the rule (docs/fdm-design-rules.md §4); under that you get a warning rather than a block, because it is your call. */

plate_t  = 8;     /* Chosen so every internal transition lands ON a layer boundary in the print orientation. At 0.2 mm layers, 2.4 puts the pocket floor and all three staged layers at print z 1.2 / 1.4 / 1.6 / 2.4. At 2.5 they all land mid-layer and the staging resolves on a slicer tie-break rather than on the geometry. */
corner_r = 1.5;     /* Rounding on the outline corners. Feeds the overlap floor above — the bigger this is, the more lap the corners need. */

/* [Centre opening — lip, sized to the PORT] */
/* The USB-C receptacle shell is 8.94 x 3.16 mm, fixed by the USB spec; the plug's metal tongue is 8.34 x 2.56 and passes through easily at this size. */
port_w  = 9.3;      /* Hugs the 8.94 mm receptacle shell with ~0.18 mm a side. */
port_h  = 3.6;      /* Ditto against the 3.16 mm shell height. */
port_r  = 2.0;      /* Clamped to a stadium shape by rrect2d(). */
lip_t   = 0.8;      /* Thickness of the lip itself. NOT how far a plug must reach: with a front protrusion the port sits lip_t + prot_t back, and the echo reports that figure separately as the port recess. */
lead_in = 0.5;      /* 45 degree chamfer on the outermost face, to guide a plug in. Printed back-face-down this is a TOP-face feature, so it is a lead-in only — it does not relieve elephant's foot, which is a first-layer effect. */

/* [Centre opening — rear relief, clears the connector's BOSS] */
boss_w = 13.4;      /* <<CONFIRM>> width NOT yet measured, still photo-scaled, and it feeds the fit. */
boss_h = 8.0;       /* MEASURED. Height of the connector's raised boss. */
boss_r = 2.0;
boss_clear = 0.25;  /* REAL clearance per side, on top of fdm_hole_comp. fdm_hole_comp only cancels print shrink — it lands the feature ON nominal, which for a pocket means printing line-to-line on the boss. Fit needs its own allowance. */
pocket_chamfer = 0.4;   /* Chamfer at the pocket mouth. That mouth is the bed face, so this costs nothing and eases the boss in. 0 = none. */

/* [Raised rectangle protrusion] */
prot_w = 13.5;      /* MEASURED */
prot_h = 6.1;       /* MEASURED */
prot_t = 4.9;       /* <<CONFIRM>> how far it stands proud. NOT measured. */
prot_r = 1.5;       /* Corner rounding. */
prot_face = "front";    /* "front" = the visible side (-Z). "back" = toward the connector (+Z). */

/* [Half-circle notches in the Y edges] */
/* Semicircular cutouts bitten out of the top and bottom edges. These are CLEARANCE features: the fitting goes into a tight space and the notches are what lets it sit there, so they are not optional and not decorative. Removing them is not a fix for anything.

The consequence is accepted rather than avoidable. At overlap 0 the plate is already only as large as the aperture, so any notch necessarily reaches past the aperture edge and opens a gap into the case across its chord — currently 1.95 mm. The guard reports the size of that gap so it stays a known quantity; it is not asking for the notches to be removed. Size them by what has to clear, then read the number.

Where overlap > 0 there is a second, avoidable failure: a notch bigger than the lap severs it. At overlap 2.5 the ceiling is about 1.9. */
notch_r = 2.85;      /* Radius, set by the obstruction being cleared. */
notch_x = 0;        /* X offset from centre. Both notches share it; use notch_mirror to put one each side instead. */
notch_mirror = false;   /* true -> top notch at +notch_x, bottom at -notch_x. */

/* [Screws] */
/*
MEASURED with calipers across the connector's own flange holes:

    inner edge to inner edge = 16.90 mm
    outer edge to outer edge = 22.70 mm

    centre-to-centre = (16.90 + 22.70) / 2 = 19.80 mm
    hole diameter    = (22.70 - 16.90) / 2 =  2.90 mm   -> M2.5, not M2
*/
screw_d    = 2.9;   /* MEASURED. Clearance for M2.5. If the screws instead thread INTO this plate, drop to about 2.1 for a self-tap pilot rather than leaving it at clearance. */
screw_span = 19.8;  /* MEASURED. THE critical dimension. */
cbore_d    = 0;     /* Counterbore diameter, 0 = none. An M2.5 socket head wants 4.5. */
cbore_h    = 1.2;   /* Counterbore depth, measured from the PLATE face. */

/* [Pocket -> lip transition — the two-bridge trick] */
/*
Printed back-face-down, the layer that closes over the pocket is the lip, and the lip HAS THE PORT HOLE IN IT. That is not a plain bridge: the printer would be asked to draw the hole's outline in mid-air, which is the classic "bridge with a hole in it" and comes out as spaghetti.

The two-bridge trick (Hackaday calls it a sacrificial bridge; nophead called it hanging holes) fixes it. Here it runs over THREE layers, and the point is that each layer does exactly ONE thing — no layer ever has to lay a straight run and a curve in the same pass.

Layer 1, THE TWO BRIDGE, is the first layer over the pocket. The opening is a full-height slot, pw x bh. What gets laid is two strips spanning bh wall-to-wall, each anchored at BOTH ends.

Layer 2, THE RECTANGLE, closes the opening to a plain pw x ph rectangle with square corners. The two remaining sides are laid here, bridging pw onto the strips.

Layer 3, THE ROUNDED CORNERS, becomes the real port, port_r rounding and all. The only new material is four small fillets, each sitting on the solid rectangle below, so the curve is never drawn in air.
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

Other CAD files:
models/gridfinity-foot-negative/gridfinity-foot-negative.scad
docs/openscad-basics/01-shapes-and-transforms.scad
docs/openscad-basics/02-combining-shapes.scad
docs/openscad-basics/03-values-not-variables.scad
docs/openscad-basics/04-library.scad
docs/openscad-basics/04-modules-and-functions.scad
docs/openscad-basics/05-loops-lists-and-2d.scad
docs/openscad-basics/06-a-real-part/m3-spacer.params.scad
docs/openscad-basics/06-a-real-part/m3-spacer.scad
models/petg-temp-tower/petg-temp-tower.scad
models/usbc-panel-plate/draw2d.scad
models/usbc-panel-plate/flange-check.scad
models/usbc-panel-plate/usbc-panel-plate.scad

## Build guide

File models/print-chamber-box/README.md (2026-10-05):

# print-chamber box — moved

The print-chamber box, and the firmware of the node it holds (`firmware/print-chamber.yaml`), moved to
their own repository on 4 Oct 2026, with their history. The box is now the **air-quality monitor**, in the
[**air-quality-monitor**](https://github.com/AlonRR/air-quality-monitor) repository, and work on either happens there.

The rest of the chamber family - the chamber-sensor notes and the node in service - moved on 5 Oct 2026
to [**printer-enclosure**](https://github.com/AlonRR/printer-enclosure), also with their history.

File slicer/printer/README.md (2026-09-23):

# Printer presets

One file, and it is the only printer preset this machine has.

## `Original Prusa i3 MK3S & MK3S+ - Copy`

**The "- Copy" suffix is PrusaSlicer's, not a mistake.** When you modify a *system* preset and
save it, PrusaSlicer writes a user preset named `<system name> - Copy`. That is why no user preset
called `Original Prusa i3 MK3S & MK3S+` exists to be a copy *of*: the original is in the vendor
bundle, not in `AppData`.

**Do not rename it here.** The filename is the preset's identity — PrusaSlicer matches by name, and
the repo-vs-live comparison matches by basename. Renaming the master would make it look like a
different preset and hide any future drift.

| | |
|---|---|
| Inherits | `Original Prusa i3 MK3S & MK3S+` (system) |
| Printer model | MK3S, variant 0.4 |
| Nozzle | 0.4 mm |
| Keys | 91 |

**Why it is versioned.** It was unversioned until 23 Sep 2026 and it is the *only* printer preset
present, so a PrusaSlicer reinstall or a new machine would have lost the printer configuration
outright with nothing to restore from. It is stored LF per `.gitattributes`; the live copy is CRLF,
which PrusaSlicer writes and which is not drift — compare with `diff --strip-trailing-cr`, or every
line reads as changed.

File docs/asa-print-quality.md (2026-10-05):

# Getting better ASA prints — Prusa MK3S+ in a Lack enclosure

Researched 29 Aug 2026. Ordered by expected payoff per unit of effort, not by topic.

**Items 1 and 2 are done** — applied to the ASA profiles and installed into PrusaSlicer.
Items 3–6 have not been: nothing else was changed.

The setup this is written against: **Prusa MK3S+, open frame, inside an IKEA Lack enclosure
closed since 19 Sep 2026 (one side was left open for venting until then), printing
Inslogic ASA at 255 °C / 100 °C bed with 20 % fan — and a glue stick on the sheet for every
print, on every material.** That last one is not incidental: it removes the prerequisite from
item 2 and changes how the sheet gets cleaned in item 3. Some of the advice below is generic ASA
practice; the first item is specific to these profiles and is the one worth reading first.

---

## 1. The minimum layer time in the ASA profile is unreachable — free fix, biggest effect

`Inslogic ASA` sets `slowdown_below_layer_time = 15`, meaning *"never let a layer finish in
under 15 seconds."* It also sets `min_print_speed = 15`, meaning *"never slow below 15 mm/s to
achieve that."* **The second setting silently overrides the first on any small part.**

The proof is already in this repo. The vase stem that printed badly was a 21.8 mm single-wall
tube, so each layer is one loop of

    π × (21.8 − 0.45) = 67.1 mm of extrusion

| | Longest layer time the floor allows | What the profile asked for | Measured |
|---|---|---|---|
| `Inslogic ASA` (`min_print_speed = 15`) | 67.1 / 15 = **4.47 s** | 15 s | **5.01 s** |
| `Inslogic ASA - thin wall` (`min_print_speed = 5`) | 67.1 / 5 = **13.4 s** | 10 s | **10.01 s** |

Both measurements land exactly where the arithmetic puts them — the base profile a little over
4.47 s once acceleration and the Z move are added, the thin-wall profile at precisely its 10 s
target because 10 s needs 6.71 mm/s, which clears the 5 mm/s floor.

So the general ASA profile has been asking for a 15 s minimum layer time and **getting 5** — a
3.4× shortfall — on exactly the parts that need it most. Small cross-sections are where heat
accumulates fastest and where a bead lands on a layer that has not set.

**This also revises what the thin-wall experiment proved.** [The Inslogic
README](../slicer/filament/inslogic/README.md) records three changes — fan 20 → 70 %, layer
time → 10 s, temperature 255 → 250 °C — and concludes the cause was under-solidification. That
conclusion stands. But the change that *did the work* is a fourth one the write-up never
mentions: `min_print_speed` 15 → 5. Without it the 10 s layer time is unreachable too, and
`slowdown_below_layer_time` was actually *lowered* (15 → 10), which reads like a reduction in
cooling time and is the opposite of what happened.

### The change

| Key | Was | Now | Status |
|---|---|---|---|
| `min_print_speed` | 15 | **5** | ✅ **Applied 29 Aug 2026**, installed 30 Aug — `Inslogic ASA` and `Inslogic ASA @0.8 nozzle` |
| `max_fan_speed` | 20 | 45 | ❌ **Not applied.** See below |
| `min_fan_speed` | 20 | 20 | Unchanged either way — bulk ASA must not get more cooling |

Measured by slicing a 21.8 mm single-wall tube — the vase-stem geometry — with everything held
constant except the floor, using the CLI's `--min-print-speed` override so exactly one variable
moved:

| | Floor | Layer-time target | Fan | Slowest move | Actual layer time | Print time |
|---|---|---|---|---|---|---|
| `Inslogic ASA`, before | 15 | 15 s | 20 % | 15.00 mm/s | **4.47 s** | 9 m 28 s |
| `Inslogic ASA`, after | **5** | 15 s | 20 % | 5.00 mm/s | **13.41 s** | 23 m 43 s |
| `- thin wall`, for reference | 5 | 10 s | 70 % | 6.70 mm/s | 10.01 s | 18 m 14 s |

**It costs nothing on ordinary parts.** A 40 mm solid cube and a mid-size probe holder slice to
*identical* times either way — 1 h 37 m 03 s and 41 m 30 s respectively, before and after. The
floor only engages once a layer is small enough to hit it, which is exactly where it should.

The 2.5× on the tube is not a cost of the fix; it is the cooling time the profile has been
asking for since July and silently not getting.

### The fan half was deliberately left out

The original proposal paired the floor with `max_fan_speed = 45`, so that
`fan_below_layer_time = 20` would ramp cooling on short layers only. **That was not applied**,
because 45 % is an interpolation between two proven points — 70 % validated on a single wall
with no cross-section to delaminate, 20 % validated on bulk ASA — and not a result.

Leaving it out is safe on its own terms: more layer time at the same fan speed is strictly more
solidification, since the nozzle deposits the same energy per layer either way and the part is
cooling throughout. The fan ramp would make short layers better still. It needs a test print
first.

---

## 2. The bed was 5–10 °C below what Prusa uses — ✅ fixed 30 Aug 2026

**Now 105 °C first layer / 110 °C**, on `Inslogic ASA` and `Inslogic ASA @0.8 nozzle`, verified
in the sliced G-code (`M190 S105` then `M140 S110`). The two `- thin wall` profiles were left at
100/100 — they are the only print-validated ASA profiles here and vase-mode parts have almost no
cross-section to warp.

It was 100/100 °C, the top of Inslogic's 80–100 range. [Prusa's own ASA
guidance](https://help.prusa3d.com/article/asa_1809) is **105 °C first layer / 110 °C after**,
and the general consensus for ASA is 105–110. A hotter bed keeps the lower layers soft longer,
so the part relieves stress instead of curling the corners up.

The Inslogic README already named this as the first thing to try if parts lift. There is no
reason to wait for a failed print to find that out, which is why it was simply applied.

**The one risk that comes with it is already covered here.** ASA on a **smooth PEI** sheet at
110 °C can bond hard enough to tear PEI off the sheet on removal — [a documented Prusa-forum
failure](https://forum.prusa3d.com/forum/original-prusa-i3-mk3s-mk3-how-do-i-print-this-printing-help/prusament-asa-sticking-too-well-on-pei-sheet/),
and the same over-adhesion mechanism the PETG profiles in this repo avoid by running a 70 °C
bed. Prusa's answer is a thin **glue-stick layer as a release agent**, not a lower bed — and on
this machine glue goes down for every print anyway.

So there is no prerequisite: **raise the bed and print.** The caveat is recorded because it is
the reason the glue matters rather than being cosmetic, and because it is what would bite if
that habit ever lapsed — a bare smooth sheet plus a 110 °C ASA first layer is how PEI gets
pulled off.

---

## 3. Bed preparation and brim — free, and the most common actual cause

- **Sheet cleaning, for a glue user:** the usual "IPA before every print" advice does not apply
  here, and following it would make things worse — **IPA does not dissolve PVA glue**, it smears
  it into a patchy film, which is uneven first-layer adhesion by another name. The right routine
  with a glue stick is **warm water**: PVA is water-soluble, so wash the sheet off periodically
  and re-glue rather than topping up indefinitely over old layers. Keep dish soap and IPA for
  when the sheet is bare and actually oily, which is
  [Prusa's escalation](https://help.prusa3d.com/article/first-layer-issues_1804) for the
  no-glue case.
- ~~**Brim, at least 5 mm**, on anything tall or with a small footprint.~~
- ~~**Use PrusaSlicer's draft shield**~~, a wall printed round the part to hold warm still air
  against it.

⛔ **RETIRED 2 Oct 2026 — no skirt, no brim, no draft shield, on anything.** Alon's rules: *never
print a skirt*, and *a part designed correctly does not need a brim either*. The shield was a
stand-in for closing the enclosure's open side, and **the enclosure closes fully**; it also costs
filament on every layer, which is why the first print to use it was stopped. ASA prints with the plain
`0.2mm QUALITY @MK3 - no skirt, no brim, no crossing perimeter`, and warping is answered in the design
— rounded corners in plan view first ([fdm-design-rules §5b](fdm-design-rules.md)).
`scripts/scad-check.sh` now fails any G-code with a skirt or a brim, and
`scripts/patch_print_profiles.py` turns all three off in every preset.

The ASA profile below was **deleted on 2 Oct 2026**, from the repo and from PrusaSlicer's presets.
What follows explains the mechanism, which still matters: a draft shield **is** a skirt.

~~Every print profile in `slicer/print/` strips skirt and brim by default — the right call for
most parts and the wrong one for ASA. So there is now an ASA-specific one:
**`0.2mm QUALITY @MK3 - ASA brim + draft shield`**, built 30 Aug 2026 from the plain 0.2 profile.~~

### ⛔ The draft shield is drawn from the skirt — with `skirts = 0` it prints nothing

This is the reason the profile exists rather than a note telling you to tick two boxes. Every
0.4-nozzle profile in this repo sets `skirts = 0`, and turning the draft shield on without
fixing that produces **silence, not an error**.

Measured on a 40 mm cube, one variable at a time:

| Settings | Skirt/brim sections | On how many layers |
|---|---|---|
| Profile as-is | 0 | 0 |
| `draft_shield = enabled`, `brim_width = 5`, **`skirts = 0`** | **1** | **1** — that is the brim. **No shield at all** |
| the same plus **`skirts = 1`** | **200** | **200** — every layer of the 40 mm part |

200 layers is 40 mm / 0.2 mm, so the shield runs the full height of the object, which is what
it is for.

The profile therefore changes **five** keys, not two:

| Key | Base | ASA profile | Why |
|---|---|---|---|
| `brim_width` | 0 | **5** | Prusa's baseline is ≥ 3 mm; ASA earns more |
| `brim_type` | `no_brim` | `outer_only` | Warp lifts the outside edges; a brim inside holes buys nothing |
| `draft_shield` | `disabled` | `enabled` | Full object height, not `limited` |
| `skirts` | 0 | **1** | Without this the shield is silently absent |
| `skirt_distance` | 2 | **8** | The brim now sticks out 5 mm; at 2 mm the shield would print into it |

The last one is the quiet one: change the brim without changing the skirt distance and the
shield lands on top of the brim.

---

## 4. Chamber temperature — the real ceiling, and it is gated on a measurement

ASA wants a **warm, still chamber: 40–50 °C is the usual target**, and sources go as high as
70. ✅ **The enclosure has been closed since 19 Sep 2026, and an ASA print now holds the chamber at
45–46 °C** (2 Oct 2026, room 26.6 °C) — inside the target on bed heat alone. Until then one side
was deliberately open, which kept the chamber near room temperature and the airflow across the part
asymmetric. Details: [chamber-sensor measurements](https://github.com/AlonRR/printer-enclosure/blob/main/docs/chamber-sensor/measurements.md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).
⚠️ **What closing has not yet been checked against is the Einsy** — see below; its bay has not been
read with the box closed during an ASA print.

**Do not simply close it — but the exposure is smaller than this page long claimed.** ⚠️ **CORRECTED 4 Sep 2026: the PSU is ALREADY OUTSIDE the enclosure.** Alon moved it out when he built the box, so every statement here and in `CLAUDE.md` that "the Einsy board and the PSU sit inside the frame" has been false since the enclosure was built, and the risk was being overstated in every document that repeated it. **Only the Einsy is inside.** That removes the larger heat source of the two — a PSU dissipates its own losses under bed load *and* stirs the bay with its fan — so the remaining question is Einsy-only. The
failure mode is documented and specific: users printing ABS/ASA in a closed enclosure report
**`TMC DRIVER OVERTEMP`** faults, and the practical advice is either active cooling on the
electronics box or moving the board outside the enclosure. Reports conflict on whether an
MK3S+ tolerates a closed enclosure — some run doors-closed without trouble — which is exactly
the situation where measuring beats reading forum posts.

**The gating step was the chamber sensor, and it exists:** a node has measured the chamber air
since September ([chamber-sensor](https://github.com/AlonRR/printer-enclosure/blob/main/docs/chamber-sensor.md)). The bay has no probe of its own (Alon,
3 Oct 2026): it is read from the Einsy's own thermistor, at the printer.

⚠️ **The DHT11 is marginal for this specific job.** Ten are on hand, but its range tops out at
**50 °C** — the top of the target band — with ±2 °C accuracy and 1 °C resolution. It will tell
you "the chamber is 44, not 24", which is enough to decide whether closing the side did
anything. It will not characterise a 50 °C chamber, and it saturates precisely where the
interesting reading is. An AHT20 or SHT31 (±0.3 °C, to 120 °C) is the right part if this
becomes more than a yes/no check.

A staged approach that needs no purchase: close the open side **partially**, print, and let the
printer's own `TMC DRIVER OVERTEMP` guard be the safety net — it is a real firmware check, not
something that has to be inferred. Increase closure until either the print quality stops
improving or the printer complains.

---

## 5. Dry the filament — 80 °C for 4–6 h

Inslogic's data sheet says **80 °C, 4 h**; general ASA guidance says 80–90 °C for 4–6 h. ASA
absorbs roughly **0.2–0.4 % water in 24 h at 50 % RH** — less desperate than nylon or TPU, but
enough to matter on a spool that has been open for weeks.

Wet ASA looks like a bad profile, which is why it is worth ruling out first: **popping or
hissing at the nozzle, stringing, rough or pitted walls, small bubbles, inconsistent extrusion,
weak layers.** If a print has gone worse over time with no setting changed, moisture is the
first suspect, not the profile.

There is no dryer in this lab. The options, cheapest first:

- A kitchen oven at its lowest setting, if it will hold 80 °C — many will not go that low
  accurately, and ASA's Tg is 108 °C so there is margin, but an oven that overshoots to 120 °C
  will fuse the spool.
- The **12 V 50 W PTC heater** — ⚠️ **no longer available to this build.** Reallocated to the active drybox on 3 Sep 2026 — that build moved to its own repository; reviving this needs a second element at ₪39. In a sealed box, 50 W
  is modest but a small insulated box is a small volume. Needs a >4 A 12 V supply, which the
  PD trigger board is not.
- Desiccant storage to stop the problem recurring: filamentcenter sells 2 kg alumina at ₪89 and
  2 kg indicating silica gel at ₪69, orange-to-clear so it shows when it is spent.

Drying fixes a wet spool. Storage stops you needing to.

---

## 6. Things to leave alone

- **Do not raise the fan on bulk ASA.** The 20 % is deliberate and the reason is written up in
  the Inslogic README. The 100 % on Inslogic's data sheet is boilerplate — it appears
  identically on all four of their sheets, for four materials whose cooling needs are nothing
  alike. Item 1 above raises the fan *only for short layers*, which is a different thing.
- **Do not chase nozzle temperature first.** 255 °C sits mid-band for the speeds this printer
  runs and 260 is available if layer bonding is genuinely weak — but temperature is the knob
  people reach for when the real problem is a cold chamber or a wet spool, and it is the one
  most likely to trade one defect for another (stringing, blobs).
- **Do not seal the enclosure before item 4's measurement.** The electronics are inside it.

---

## Order to actually do this in

1. ~~**Raise the bed to 105/110 °C.**~~ ✅ **Done 30 Aug 2026**, installed and verified in the
   G-code. No prerequisite was needed — the glue stick that makes it safe is already standing
   practice here. `- thin wall` and `- thin wall, flat base` deliberately left at 100/100.
2. ~~**Fix `min_print_speed`** (item 1).~~ ✅ **Done.** Applied to both Inslogic ASA profiles
   29 Aug 2026, installed on 30 Aug once PrusaSlicer was closed, and confirmed against the live
   config: the same tube now slices with a slowest move of 5.00 mm/s and a 13.41 s layer,
   against 15.00 mm/s and 4.47 s before.
   The install waited a day because PrusaSlicer was open, and it rewrites its config folder on
   exit — a copy made while it is running is silently undone when you quit. Check first with
   `Get-Process prusa-slicer*`.
3. ~~**Brim and draft shield** on the next tall ASA part.~~ ⛔ **Retired 2 Oct 2026** — no skirt,
   no brim and no shield, ever; see item 3 above. Design the part not to need them.
4. **Dry a spool** and reprint something that came out badly. Rules out the variable that
   masquerades as everything else.
5. **Then** the chamber sensor and closing the enclosure side — the biggest effect, the most
   work, and the only one that can damage hardware if done in the wrong order. Designed in
   [chamber-sensor.md](https://github.com/AlonRR/printer-enclosure/blob/main/docs/chamber-sensor.md): three measurement points rather than one, and the
   electronics-bay probe is the one that makes the rest safe to attempt.

Steps 1–4 need no purchase and no hardware. Step 5 needs a sensor wired to an ESP32 that is
already at the printer.

---

## See also

- **[Annealing, and plastic parts that carry load while hot](annealing-and-hot-service.md)** — what
  annealing does and does not do to ASA (amorphous, so no crystallinity to gain and no HDT rise), a
  95 °C schedule, why a preloaded flexure must never be annealed under load, and why HDT is not a
  service temperature once a part is loaded above the test case.

## Sources

- [ASA — Prusa Knowledge Base](https://help.prusa3d.com/article/asa_1809) — 105/110 bed, enclosure, glue stick on smooth PEI, brim ≥ 3 mm
- [First layer issues — Prusa Knowledge Base](https://help.prusa3d.com/article/first-layer-issues_1804) — IPA, then dish soap
- [Prusament ASA sticking too well on PEI](https://forum.prusa3d.com/forum/original-prusa-i3-mk3s-mk3-how-do-i-print-this-printing-help/prusament-asa-sticking-too-well-on-pei-sheet/) — the over-adhesion failure
- [How to succeed when 3D printing with ASA — MatterHackers](https://www.matterhackers.com/articles/how-to-succeed-when-3d-printing-with-asa-filament)
- [How to stop warping in ABS & ASA — Eolas Prints](https://eolasprints.com/en-us/blogs/advanced-3d-printing/fix-warping-abs-asa-guide) — chamber 50–70 °C, fan off or very low
- [Understanding chamber heating — ThreeDimensionPrinters](https://threedimensionprinters.com/understanding-chamber-heating-why-ambient-temperature-matters-for-abs-and-asa/) — 40–50 °C enclosure, no drafts
- [How hot can enclosure get? — Prusa forum](https://forum.prusa3d.com/forum/original-prusa-i3-mk3s-mk3-user-mods-octoprint-enclosures-nozzles/how-hot-can-enclosure-get/) and [Electronics in or out the enclosure?](https://forum.prusa3d.com/forum/original-prusa-i3-mk3s-mk3-improvements-archive/electronics-in-or-out-the-enclosure/) — `TMC DRIVER OVERTEMP`, Einsy placement
- [Does ASA filament need drying? — goodprints3d](https://www.goodprints3d.com/blogs/3d/does-asa-filament-need-to-stay-dry-or-do-people-overstate-the-moisture-problem) and [ASA drying temperature — 3dtrcek](https://3dtrcek.com/en/blog/post/asa-drying-temperature-how-to-properly-dry-filament-for-best-prints-2) — 0.2–0.4 % water in 24 h, 80–90 °C, wet symptoms
- Inslogic ASA Technical Data Sheet rev. 12.02.2024 — figures transcribed in
  [`../slicer/reference/inslogic-filament-data.md`](../slicer/reference/inslogic-filament-data.md);
  the PDF itself is Inslogic's and is not redistributed here

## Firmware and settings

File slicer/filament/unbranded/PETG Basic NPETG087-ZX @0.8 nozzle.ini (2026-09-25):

# Unbranded PETG Basic NPETG087-ZX — Prusa MK3S+, 0.8 nozzle
# No manufacturer exists for this filament; the SKU is its identity.
# No vendor nozzle guidance exists at all, so 0.8 is neither endorsed nor
# excluded by a data sheet; this profile exists because that is how this
# printer is often run here.

bed_temperature = 75
bridge_fan_speed = 50
chamber_minimal_temperature = 0
chamber_temperature = 0
compatible_printers = 
compatible_printers_condition = nozzle_diameter[0]==0.8 and printer_model!="MK2SMM" and printer_notes!~/.*MINI.*/ and printer_notes!~/.*PG.*/ and ! single_extruder_multi_material
compatible_prints = 
compatible_prints_condition = 
cooling = 1
cooling_perimeter_transition_distance = 0
cooling_slowdown_logic = uniform_cooling
custom_parameters_filament = ""
disable_fan_first_layers = 3
enable_dynamic_fan_speeds = 0
end_filament_gcode = "; Filament-specific end gcode"
extrusion_multiplier = 1
fan_always_on = 1
fan_below_layer_time = 20
filament_abrasive = 0
filament_colour = #FF8000
filament_cooling_final_speed = 3.4
filament_cooling_initial_speed = 2.2
filament_cooling_moves = 4
filament_cost = 36
filament_density = 1.27
filament_deretract_speed = nil
filament_diameter = 1.75
filament_infill_max_crossing_speed = 0
filament_infill_max_speed = 0
filament_load_time = 0
filament_loading_speed = 28
filament_loading_speed_start = 3
filament_max_volumetric_speed = 20
filament_minimal_purge_on_wipe_tower = 15
filament_multitool_ramming = 0
filament_multitool_ramming_flow = 10
filament_multitool_ramming_volume = 10
filament_notes = "Unbranded OEM PETG Basic, SKU NPETG087-ZX, batch B2204001W.\n\nTHERE IS NO BRAND. Verified from the packaging 3 Sep 2026: no manufacturer on the spool label, none on the carton, none in the carton parameter table. The carton is generic OEM - a printed checklist of product lines (PLA Basic / PLA+ / PLA Pro / PLA Matte / PLA HS / PLA Rainbow / PLA Silk / PETG Basic / PETG HS / ABS / ASA / PA / TPU 95A) with a tick-box for the one inside. The SKU is the only identity this filament has, which is why it is in the filename.\n\nNOT FILLAMENTUM, though it was described that way. Ruled out three ways: Fillamentum names its PETG colours (Black Soul, Ghost White, Vertigo Grey) and never 'Basic'; Fillamentum publishes 235-255 C / 65-75 C at +/- 0.05 mm against this spool's 230-260 C / 70-90 C at +/- 0.03 mm; and 36 ILS/kg against a premium Czech brand at several times that.\n\nCOST: 36 ILS/kg - the cheapest filament in this repo by volume at 0.046 ILS/cm3, about 8 % under Yasin3D PETG.\n\nSPOOL LABEL - the only real source, since the vendor's web page publishes no temperatures at all:\nPrinting temp 230-260 C. Bed 70-90 C. Diameter 1.75 mm.\nCARTON: tolerance +/- 0.03 mm, between Inslogic's +/- 0.02 and Fillamentum's +/- 0.05.\n\nDRYING: 50 C for 4 h. INHERITED, NOT THIS SPOOL'S SPEC. This filament publishes no drying schedule at all. 50 C / 4 h is the figure from Inslogic's PETG Pro TDS - a real vendor number for the same material, which is a better basis than the 55-65 C ranges quoted generically online. Do not go hotter. PETG's glass transition is around 80 C, but spools deform and windings FUSE well below that, and a welded spool is unrecoverable; 50 C leaves 30 C of headroom and the extra speed from 65 C does not pay for the risk. Method: printer bed at 50 C with a cardboard box over the spool, a gap left so moist air can escape rather than recirculate. NOT a kitchen oven - domestic ovens cycle far outside their setpoint at low temperatures. NOT inside the Lack enclosure - the Einsy board lives in that frame.\n\nTHERE IS NO TDS. No density, no drying schedule, no mechanical data, no glass transition. Every other profile in this repo is derived from a vendor data sheet; this one cannot be. It has to be settled by a calibration print, and the numbers below are a starting point rather than a specification.\n\nDENSITY IS AN ASSUMPTION, NOT A SPEC. 1.27 g/cm3 is the generic figure for PETG. It feeds cost-per-volume and the filament-used estimate, so if either matters, weigh a known length and correct it.\n\nBED 75/75, 5 C above the bottom of the label's 70-90 C range. MEASURED ON THIS PRINTER, NOT INHERITED: the schubox warped at 70/70; the lid printed at 75/75 with no warping. Same filament, same sheet, same large flat-bottomed geometry - the bed temperature is what changed, which is why this is the one setpoint here backed by a print rather than by a data sheet. The label permits 90 C, which makes it more tempting than the Inslogic case and no less damaging: PETG at that temperature bonds to a smooth PEI sheet strongly enough to tear PEI off it on removal. Here 90 C is INSIDE vendor spec, which changes nothing about the sheet. If the first layer will not stick at 75 C, raise toward 85/90 - and put down a thin glue-stick release layer first, which is what makes the higher bed safe rather than what makes it work.\n\nTEMPERATURE 240 C sits mid-band in the label's 230-260 C and
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

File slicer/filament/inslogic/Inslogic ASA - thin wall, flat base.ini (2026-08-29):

# Inslogic ASA — thin stem with a FLAT PLATE base — Prusa MK3S+, 0.4 nozzle
#
# Sibling of `Inslogic ASA - thin wall`. Identical in every respect except one value:
# disable_fan_first_layers is 10 instead of 4.
#
# Use for a part that is mostly thin (short layer times, needs the 70 % fan) but
# starts with a wide flat plate on the bed that must NOT be fan-cooled.
# Built for `Stem_for_Rose_5cm.stl` — leaves print flat as a 106.9 mm plate over
# layers 1-9, then a solid ~5.75 mm stem runs to 198 mm.
#
# WHY THE ONE CHANGE MATTERS
# The leaves are meant to be BENT UP by hand after printing. That makes interlayer
# bonding inside the leaf plate a functional requirement, not a cosmetic one: an
# ASA plate whose upper layers were laid down under 70 % part cooling snaps when
# bent instead of deforming. At disable_fan_first_layers = 4 the fan reaches full
# speed at layer 5, so five of the nine leaf layers get chilled. 10 covers the whole
# plate, then 70 % starts for the stem where the vase print proved it is needed.
#
# This is NOT a bed-adhesion setting. Adhesion here is handled by Magigoo (Original
# — label covers PLA/ABS/PET-G/TPU; ASA is not named but behaves like ABS), which is
# why no brim is used despite a 106.9 mm flat span. Magigoo grips the bottom face to
# the sheet; it does nothing for how layer 6 fused to layer 5, which is the bond that
# does the work when a leaf is bent.

bed_temperature = 100
bridge_fan_speed = 70
chamber_minimal_temperature = 0
chamber_temperature = 0
compatible_printers = 
compatible_printers_condition = nozzle_diameter[0]!=0.8 and printer_notes!~/.*MINI.*/ and printer_notes!~/.*PG.*/ and ! (printer_notes=~/.*PRINTER_VENDOR_PRUSA3D.*/ and printer_notes=~/.*PRINTER_MODEL_MK(2.5|3).*/ and single_extruder_multi_material)
compatible_prints = 
compatible_prints_condition = 
cooling = 1
cooling_perimeter_transition_distance = 0
cooling_slowdown_logic = uniform_cooling
custom_parameters_filament = ""
disable_fan_first_layers = 10
enable_dynamic_fan_speeds = 0
end_filament_gcode = "; Filament-specific end gcode"
extrusion_multiplier = 1
fan_always_on = 1
fan_below_layer_time = 60
filament_abrasive = 0
filament_colour = #FFF2EC
filament_cooling_final_speed = 3.4
filament_cooling_initial_speed = 2.2
filament_cooling_moves = 4
filament_cost = 69
filament_density = 1.05
filament_deretract_speed = nil
filament_diameter = 1.75
filament_infill_max_crossing_speed = 0
filament_infill_max_speed = 0
filament_load_time = 0
filament_loading_speed = 28
filament_loading_speed_start = 3
filament_max_volumetric_speed = 11
filament_minimal_purge_on_wipe_tower = 15
filament_multitool_ramming = 0
filament_multitool_ramming_flow = 10
filament_multitool_ramming_volume = 10
filament_notes = "Inslogic ASA, THIN STEM + FLAT PLATE BASE variant — TDS rev. 12.02.2024.\n\nUSE FOR: a part that is mostly thin/short-layer (wants 70 % fan) but begins with a\nwide flat plate that must not be fan-cooled. Built for Stem_for_Rose_5cm.stl.\nDO NOT USE FOR: normal bulk ASA parts — 70 % fan splits layers. Use 'Inslogic ASA'.\n\nDIFFERENCE FROM 'Inslogic ASA - thin wall': disable_fan_first_layers 4 -> 10. Nothing\nelse. The stem behaviour is deliberately identical to the vase profile, which was\nprint-validated 29 Jul 2026.\n\nWHY: the leaves print flat over layers 1-9 and are BENT UP by hand afterwards, so\ninterlayer bonding in that plate is structural. At 4, the fan hits full speed at\nlayer 5 and chills five of the nine leaf layers; ASA bonded under high cooling snaps\nwhen bent rather than deforming. 10 covers the whole plate.\n\nMODEL FACTS worth keeping (measured from the STL, not assumed):\n- Leaves: Z 0 to ~1.75 mm, 106.9 mm span, 3090 mm2 flat plate.\n- Stem: SOLID, ~5.75 mm diameter, no interior void at any height, up to 197.92 mm\n  (MK3S+ Z limit is 210 mm).\n- Every cross-section shrinks going up, so NO SUPPORTS are needed. Thorns are small\n  outward bumps that bridge fine.\n- Measured layer times with this cooling: leaf region ~94 s, stem ~8.8 s. The stem\n  figure is the one that matters — the print that failed sat at 5.0 s.\n\n⛔ DO NOT slice this model with the print profile '0.2mm QUALITY @MK3 - ... lightning'.\nThat profile has spiral_vase = 1 baked in (the only one of the eight that does). The\nstem is SOLID, so vase mode would hollow it into a single 0.45 mm wall with no top —\na 198 mm flagpole that would not survive handling. Use the same profile name WITHOUT\n'lightning' (vase off, 2 perimeters, 15 % infill).\n\nUNTESTED - built 29 Jul 2026."
filament_purge_multiplier = 100%
filament_ramming_parameters = "120 100 5.70968 6.03226 7 8.25806 9 9.19355 9.3871 9.77419 10.129 10.3226 10.4516 10.5161| 0.05 5.69677 0.45 6.15484 0.95 8.76774 1.45 9.20323 1.95 9.95806 2.45 10.3871 2.95 10.5677 3.45 7.6 3.95 7.6 4.45 7.6 4.95 7.6"
filament_retract_before_travel = nil
filament_retract_before_wipe = nil
filament_retract_layer_change = nil
filament_retract_length = nil
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

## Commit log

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2026-08-02 fix(slicer): correct filament profile names and vendor fields
    Three naming defects, all of which made a profile say something untrue about
    itself.
    Vendor spelling. The same vendor, Yasin3D, appeared as two different names
    across two profiles - 'Yasi3D PLA @0.8 nozzle' and 'YASIN ASA @0.8 nozzle' -
    and neither carried the right vendor in metadata: the PLA said "Generic" and
    the ASA said "Prusa Polymers" (inherited from Prusament ASA and never
    corrected). Both are now 'Yasin3D <material> @0.8 nozzle' with
    filament_vendor = Yasin3D. These two were not previously in the repo at all;
    they existed only in %APPDATA% with no backup anywhere, so they are added here
    under slicer/filament/yasin3d/.
    M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
    [Inslogic ASA - thin wall, flat base.ini, Inslogic ASA - thin wall.ini]
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2026-08-17 feat(models): close the USB-C opening down to the port itself
    The centre hole cleared the connector's whole raised boss, leaving open air
    visible around the port. It is now two levels: a 0.8 mm front lip sized to the
    receptacle (9.5 x 3.7), opening out behind into a 13.4 x 8.4 x 1.7 mm pocket
    that the boss nests into. Outline, screws and lap are unchanged.
    Panel measured at 0.6 mm, so the pocket accommodates a boss standing up to
    2.3 mm proud of the connector flange -- 1.7 mm of pocket plus the 0.6 mm the
    panel absorbs. Recorded as the thing to suspect if the plate will not sit flat.
    The lip only has to clear the plug's metal tongue, 8.34 x 2.56 mm and fixed by
    the USB spec, which 9.5 x 3.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
    [usbc-panel-plate.scad]
2026-08-17 feat(models): add half-circle notches to the plate's Y edges
    Semicircular cutouts bitten out of the top and bottom edges, radius 2 mm,
    centred by default. notch_x offsets the pair; notch_mirror puts one each side
    instead. notch_r = 0 removes them.
    Also folds in the two measured heights: exposed port area 4.7 mm (was 3.7) and
    connector boss 8.0 mm (was a photo-scaled 8.4). Both widths remain unmeasured
    and stay flagged <<CONFIRM>>, so this is not sliceable yet -- port_w in
    particular was reported as roughly 2 mm too wide, which would land near 7.5,
    under the 8.34 mm USB-C plug tongue. Cutting it on that arithmetic alone could
    produce a plate no cable fits, so it waits for the measurement.
    T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
    [usbc-panel-plate.scad]
2026-08-17 tweak(models): notch radius 2.0 -> 2.5
    Clearances re-checked and still healthy: 2.0 mm to the rear pocket, 9.1 mm to
    the nearest screw hole. Break-through into the case aperture deepens from
    1.0 to 1.5 mm.
    [usbc-panel-plate.scad]
2026-08-17 feat(models): measured boss 14.7 x 6.1; shrink plate to the opening
    Boss taken from "the port rectangle is 6.1 x 14.7". Assigned to the rear pocket
    rather than the front lip by elimination: a 14.7 x 6.1 opening in the lip would
    reopen the very gap the two-level opening exists to close. 6.1 supersedes an
    earlier 8.0 for this feature; the two numbers were reported for different
    rectangles and 6.1 arrived as a matched pair with 14.7.
    Also captures overlap dropped to 0.2 and the min_w margin commented out, which
    together shrink the plate to 23.8 x 15.4 -- essentially the aperture size.
    Two consequences the echoes now surface, neither of them errors:
    outboard of screw : 0.55 mm
    web beside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
    [usbc-panel-plate.scad]
2026-08-17 feat(models): add the 14.7 x 6.1 raised rectangle
    The measured 14.7 x 6.1 is a protrusion, not a recess, and it is in ADDITION to
    the rear pocket rather than replacing it -- so boss_w/boss_h revert to 13.4 x
    8.0 and the new prot_* parameters carry the measurement.
    prot_face selects which side it stands on. Because the outermost face is no
    longer necessarily z = 0, the cuts are now driven by computed front_z / cut_lo /
    cut_len instead of hardcoded offsets; the port opening, lead-in chamfer, Y-edge
    notches and screw holes all follow it. Without that the notches would have left
    stubs standing on the protrusion and the chamfer would have been cut into thin
    air inside the part.
    Four asserts gua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
    [usbc-panel-plate.scad]
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2026-08-17 docs: FDM design rules calibrated to this printer, plus a plate audit
    Generic guides quote a 1.2 mm minimum wall and a 0.4 mm nozzle. Neither is the
    governing number here. The profiles in this repo slice at 0.45 mm extrusion
    width, read out of the sliced G-code rather than assumed, so walls quantise to
    0.90 / 1.35 / 1.80 and vertical features to 0.2 + n * 0.15.
    That reframes the usual advice: a 1.1 mm wall is WORSE than 0.90, because it is
    two perimeters plus a 0.2 mm gap the slicer has to fudge into a void. Thickness
    between multiples buys nothing and costs solidity.
    Also captures that the slicer bridges an opening's SHORT axis, which is why the
    plate's 13.4 x 8.0 pocket is an 8 mm bridge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
    [usbc-panel-plate.scad]
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2026-08-17 fix(models): step the pocket transition on one axis, not both
    The ledge interpolated in X and Y at once, so it ran right around the opening.
    pocket_step_axis now narrows only the chosen axis and holds the other at full
    pocket size, so that pair of walls drops straight to the lip with no ledge on
    them at all.
    Defaults to "y" because Y is the governing reach: X is 2.05 mm, Y is 2.20 mm,
    so splitting Y takes the worse of the two down to 1.10 mm.
    The echoes report both axes separately now rather than only the maximum. The
    old single "ceiling reach" line hid the fact that one axis still makes the jump
    in one go, which is exactly the thing worth seeing when only one axis is
    stepped:
    ceiling r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
    [usbc-panel-plate.scad]
2026-08-17 simplify(models): plain straight ledge at the hole edge
    Two fixes and a cull.
    The ledge sat at the midpoint between hole and pocket, so it read as recessed
    rather than as a step off the opening. It now steps out from the hole edge by
    step_out per side.
    It used rrect(), so its corners were rounded. Now square() -- straight sides.
    And the machinery around it is gone: the pocket_steps loop, the interpolation,
    the min() clamping, three echo lines and two asserts, all replaced by one
    conditional cut. Nothing used the generality; it was cost without a caller.
    [usbc-panel-plate.scad]
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2026-08-17 feat(models): second straight ledge on the Y axis
    step_out/step_axis become step_x/step_y -- two independent ledges, one layer
    tall each, stacked: X steps at the lip, Y one layer above, then the pocket.
    The first ledge deliberately holds Y at the lip size rather than opening it to
    the pocket. Opening it there would take Y straight to full and leave the second
    ledge with nothing to step, which is the failure mode this shape exists to
    avoid.
    Assert now checks the stacked ledge height against the pocket depth, since two
    ledges consume twice what one did.
    [usbc-panel-plate.scad]
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2026-08-17 fix(models): ledge 1 steps X and Y, ledge 2 steps X only
    Had the shape wrong. It was X first then Y; it should be both axes together on
    layer 1 -- which is what compensates for the opening's corner rounding -- and X
    alone on layer 2, with Y holding where layer 1 left it.
    Collapses step_x/step_y to a single step, since both ledges now use the same
    amount and only differ in which axes move.
    Echoes the resulting bridge span rather than just the step size, because the
    span is the thing the ledges exist to reduce and it was not visible anywhere:
    bridge span : 4 mm after the ledges (was 4.4 mm)
    [usbc-panel-plate.scad]
2026-08-17 docs(models): echo per-layer reach in print order, flipped
    Printed back-face-down the ceiling closes going UP, so the transitions run
    pocket -> L2 -> L1 -> lip, and the ledges sit at the LIP end -- after the large
    reach has already been made, not before it:
    pocket->L2 : X 1.65 Y 2.0 <-- the big one
    L2->L1 : X 0.2 Y 0
    L1->lip : X 0.2 Y 0.2
    The single "ceiling reach: X 2.05, Y 2.2" line hid this. It reports the total
    gap between lip and pocket, which says nothing about how that gap is divided
    across layers, and dividing it is the entire point of the ledges.
    No geometry change -- this is diagnostics only. Whether the placement is right
    is a judgement for the operator: two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
    [usbc-panel-plate.scad]
2026-08-17 feat(models): export in print orientation, back face on the bed
    flip_for_print rotates 180 about X at the call site, so the STL arrives already
    oriented and no longer needs flipping in the slicer. The part spans -prot_t ..
    plate_t before rotation, so it is lifted by plate_t to put its lowest point back
    on z = 0.
    Verified from the exported STL rather than the preview: min_z 0, size_z 4.0
    (2.5 plate + 1.5 protrusion), manifold yes.
    Set flip_for_print = false to work in design orientation, which is what every
    comment in the file describes -- the geometry is still authored front-at-z-0 and
    only the final call is rotated, so nothing internal has to be read upside down.
    [usbc-panel-plate.scad]
2026-08-17 feat(models): ledges are a Y-grown slot then a rectangle
    Layer 1 keeps the lip's rounded slot profile and grows it in Y only. Layer 2 is
    a plain rectangle, and the square corners are what take out the slot's rounding
    before the ceiling closes over it.
    Replaces the previous pair, which stepped X and Y as two squares and left the
    rounded ends untouched -- so the corners were still curving inward under the
    bridge, which is the thing the ledges were meant to remove.
    Verified from the exported STL with thin slices through each ledge rather than
    from the preview: z 1.35 is a square-cornered rectangle, z 1.55 is the rounded
    slot.
    Drops the per-layer reach echo added last commit. It described the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
    [usbc-panel-plate.scad]
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2026-08-18 fix(models): apply all 16 findings from the sequential review
    The headline is not any single geometry change: every echo and assert computed
    from NOMINAL dimensions while every cut was grown by hole_comp, so each clearance
    was reported 0.15-0.30 mm better than the part had. "outboard of screw" read
    0.55 mm and was really 0.40 -- under one 0.45 mm extrusion, on the feature most
    likely to break, and quoted repeatedly as evidence the part was merely marginal.
    As-cut names (pw/ph/bw/bh/sd/nr/cbd) are now defined once at file scope and used
    by geometry, echoes and guards alike, so the audited number and the built
    geometry cannot drift apart.
    Structural:
    - min_w guard restored to screw_envelope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
    [usbc-panel-plate.scad]
2026-08-18 docs(models): parameter map — a named-measurement reference that cannot drift
    A numbered callout drawing of the plate: real outlines, a plan and a section,
    and a legend giving each number's parameter NAME and LIVE VALUE. It exists so
    both sides of a conversation about this part use the same word for the same
    measurement.
    Prior art checked first: BOSL2 already ships modules for exactly this, on the
    stated grounds that "sometimes it's hard to describe what each parameter does
    without a visual aid". There is no formal standard, but a dimensioned callout
    drawing kept beside the model is the established practice, so this follows it
    rather than inventing a notation.
    The drawing is GENERATED, n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
    [parameter-map.scad, usbc-panel-plate.scad]
2026-08-18 feat(models): two-bridge trick replaces the ledges; axes on the parameter map
    The ledges were solving the wrong problem. Printed back-face-down the layer that
    closes over the pocket IS the lip, and the lip has the port hole in it -- so this
    was never a plain bridge to be relieved, it was the classic "bridge with a hole
    in it", where the printer draws the hole's outline in mid-air.
    The two-bridge trick (Hackaday: sacrificial bridge; nophead: hanging holes)
    splits it into two anchored stages. Stage 1 opens the port out into a full-height
    slot, leaving two strips spanning wall-to-wall, each anchored at BOTH ends.
    Stage 2 closes down to the real port, its bands landing on those strips. Nothing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
    [parameter-map.scad, usbc-panel-plate.scad]
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2026-08-18 feat(models): three staged layers, each doing exactly one thing
    Drops the cross. The staging is now one job per layer, which is what makes it
    legible as well as printable -- no layer ever has to lay a straight run and a
    curve in the same pass:
    L1 the two bridge slot 9.6 x 8.8 two strips spanning 8.8 mm, anchored
    at both ends
    L2 the rectangle 9.6 x 3.9 square the other two sides bridge 9.6 mm onto
    those strips
    L3 the corners r2 fillets only laid on the solid rectangle below
    The third layer is the part the earlier attempts kept getting wrong. Closing
    straight from a rectangle to the rounded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
    [usbc-panel-plate.scad]
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2026-08-18 refactor(models): group the slicer facts as fdm_*, derive the wall thresholds
    Yes to fdm_layer_h, but the rename was the smaller half. layer_h and hole_comp
    are facts about how the part gets MADE, not decisions about what it should BE --
    each has a counterpart in the print profile and the model is wrong the moment
    they disagree. Grouping and prefixing them says so at a glance instead of leaving
    it to be discovered by a bad print. layer_h was also filed under the bridge
    block, as if it belonged to that feature, when the plate_t alignment asserts
    depend on it too.
    The larger find was fdm_extrusion_w, which was not a parameter at all. It was
    sitting in the asserts as the literals 1.35 and 1.0,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
    [parameter-map.scad, usbc-panel-plate.scad]
2026-08-18 feat(models): dimension lines and colour groups on the parameter map
    Numbered dots answered the wrong question. A dot says "this feature"; the thing
    actually needed is "this distance, between these two edges". Every measurement is
    now a real dimension line -- extension lines back to the feature, arrowheads at
    both ends, name and live value on the line -- so what is being measured is never
    inferred. Leader lines remain only for the two things that are features rather
    than spans, screw_d and notch_r.
    Colour groups the families: outline, port/raised rect, fasteners, rear pocket,
    staged bridge layers. The pocket is behind the visible face, which a drawing
    would normally show dashed; colour carr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
    [parameter-map.scad]
2026-08-18 docs(models): correct the render command in the map header
    The sed that was meant to update it failed on an unescaped backslash, so the
    committed header still gave the old imgsize and camera -- which would have
    produced a cropped drawing for anyone who copied it.
    [parameter-map.scad]
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2026-08-18 fix: harden scad-check against stale STLs; epsilon on the perimeter assert
    Two fixes, both found by running the new checker against a live edit rather
    than against the file it was written for.
    scad-check now deletes the STL before rendering. OpenSCAD leaves the previous
    STL untouched when a render fails, so every step after that was validating
    stale geometry -- and could report PASS on a model that does not build. That is
    the worst failure a verification tool can have, and it was in the tool written
    to catch exactly this class of thing.
    The edge-distance assert gets a 1e-9 epsilon. 3 * 0.45 evaluates to
    1.3500000000000001, so a design landing EXACTLY on three perimeters failed a
    bare >= co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
    [usbc-panel-plate.scad]
2026-08-18 feat(models): split guards into impossible (block) and compromised (warn)
    Asserting everything was too blunt. It meant exploring a design got blocked by
    problems that were judgement calls rather than impossibilities -- lowering
    overlap to see how small the plate could go stopped the render outright, when
    what was wanted was the part plus a clear statement of what it costs.
    BLOCK the geometry is impossible or self-contradictory: a feature vanishes,
    inverts, or cuts the part in two; an enum is misspelled. There is no
    sensible STL to produce.
    WARN it builds and prints, but something is compromised: a wall under the
    perimeter floor, a notch opening into the ca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
    [usbc-panel-plate.scad]
2026-08-18 feat(models): make the plate_w floor tunable, add edge-open screw slots
    plate_w was already at its floor, and the floor was invisible. It is the higher
    of two, and which one binds was not reported anywhere:
    COVERAGE gap_w + 2*overlap. Physics. No way around it.
    FASTENERS screw envelope + material outboard of each hole. A CHOICE, and the
    one that was actually binding: at overlap 0.5 coverage wants 24.4
    while the fasteners want 25.7.
    So "make it narrower" meant touching the fasteners, and nothing in the file said
    so. The echo now names which floor is binding and what the other would allow.
    screw_edge_margin exposes the 1.5 that was hardcoded inside min_w.
    s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
    [usbc-panel-plate.scad]
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2026-08-18 docs: state constraints in present tense, drop the changelog from the comments
    Six comments and four README passages narrated what an earlier version did and
    how it broke. Git holds that; a comment should say what the constraint IS.
    Each is rewritten forward: "1.35 used to appear as a literal" becomes "spelled as
    the literal 1.35 these would be magic numbers whose meaning lives where nothing
    can check it"; "an earlier version asserted both, which blocked exploration"
    becomes "asserting both would block exploration". Same warning, but it now reads
    as a rule rather than an anecdote, and it stays true regardless of what the file
    did last week.
    Kept in docs/fdm-design-rules.md, where the worke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
    [parameter-map.scad, usbc-panel-plate.params.scad, usbc-panel-plate.scad]
2026-08-18 fix(usbc-plate): split the coverage guard, which was false at corner_r=0
    The single test `overlap <= corner_min` conflated two different failures and
    degenerated at corner_r = 0: corner_min is then 0, the condition reads 0 <= 0,
    and it reported "the ROUNDED CORNERS fall inside the aperture" on a plate that
    has no rounded corners.
    Now two guards, one per failure:
    overlap <= 0 nothing in front of the panel is
    wider than the hole (any corner_r)
    corner_r > 0 && 0 < overlap <= corner_min straight edges cover, corners do not
    Both stay WARN. Zero lap is a deliberate choice here - the fitting is
    space-limited - so it is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
    [usbc-panel-plate.params.scad, usbc-panel-plate.scad]
2026-08-19 docs(usbc-plate): draw the flange measurement, record the notches as clearance
    flange-check.scad -> flange-check.png states the one open question in a form
    that can be answered with calipers: measure the connector flange's width A and
    height B, compare against the 23.4 x 15 aperture.
    Solid lines are values the model already knows; dashed and orange are the
    unknown. The section is cut through the HEIGHT deliberately - plate_h is
    gap_h + 2*overlap, so at overlap 0 it is exactly 15 and the plate edge lands
    precisely on the aperture edge. Cutting through the width would have been
    misleading: plate_w is pushed to 23.9 by the fastener floor, so it carries
    0.25 mm of lap the design does not rely o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
    [draw2d.scad, flange-check.scad, parameter-map.scad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]
2026-08-21 docs(fdm): how to join two printed parts - weld ASA, do not glue it
    The homelab purchasing session asked whether instant glue was the right buy
    for "bonding 3D-printed parts". It was not written down anywhere, so it had to
    be asked. Recording it here so the next session reads it instead.
    ASA and ABS solvent-weld in acetone, which fuses the parts into one piece and
    beats any adhesive. CA bonds only to the outer skin and fails by peeling the
    perimeter off the layer beneath. Acetone does not touch PLA and does not weld
    TPU, both on the shelf, so CA keeps real uses - just not as the primary plan.
    Also records that cyanoacrylate should not be mail-ordered: short shelf life,
    polymerises with age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
    [parameter-map.scad, usbc-panel-plate.params.scad]
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2026-08-29 fix(slicer): Inslogic ASA and TPU were costed at their Prusa parent's price
    Neither ever set filament_cost, so the flattener handed each one whatever its
    parent charged: 35.28 from Prusament ASA across all four ASA profiles, 82 from
    Generic FLEX and 85 from NinjaTek Cheetah TPU across the three TPU ones.
    Real prices, per 1 kg spool incl. VAT from Inslogic's Israeli distributor
    filamentcenter.co.il, checked 29 Aug 2026: ASA 69, TPU 95A 79.
    ASA was costing out at about half. The TPU numbers are the more instructive
    failure - 82 and 85 against a real 79 look like figures someone chose, and the
    only tell that nobody had was that all three files disagreed with each other
    while none matched a pr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
    [Inslogic ASA - thin wall, flat base.ini, Inslogic ASA - thin wall.ini, Inslogic ASA @0.8 nozzle.ini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]
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2026-08-29 fix(asa): min_print_speed 15 -> 5, so the 15 s minimum layer time can happen
    Inslogic ASA and Inslogic ASA @0.8 nozzle both asked for a 15 s minimum layer
    time and both capped the slowdown at 15 mm/s, which on a small part makes the
    request unreachable. Measured on the 21.8 mm single-wall tube from the July
    vase-stem write-up, one variable moved via the CLI's --min-print-speed:
    floor 15 -> slowest move 15.00 mm/s -> layer 4.47 s -> 9m28s
    floor 5 -> slowest move 5.00 mm/s -> layer 13.41 s -> 23m43s
    For reference the thin-wall profile, which already had the floor at 5, emits
    6.70 mm/s and lands on its 10 s target exactly.
    Ordinary parts are untouched: a 40 mm solid cube slices to 1h37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
    [Inslogic ASA @0.8 nozzle.ini, Inslogic ASA.ini]
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2026-08-30 fix(asa): bed to Prusa's 105/110, leaving vendor spec on purpose
    Inslogic ASA and Inslogic ASA @0.8 nozzle ran 100/100, the top of Inslogic's
    80-100 range, with a note saying to raise toward Prusa's 105/110 if parts
    lifted. There is no reason to wait for a failed print to learn that, so they
    now use Prusa's numbers outright. A hotter bed keeps the lower layers soft
    longer, so the part relieves stress instead of curling its corners up.
    Verified in the sliced G-code: M190 S105 for the first layer, M140 S110 after,
    on both the 0.4 and 0.8 profiles. Installed, and the repo matches the live
    config byte for byte.
    This is only safe because a glue stick goes down for every print here. ASA on a
    BAR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
    [Inslogic ASA @0.8 nozzle.ini, Inslogic ASA.ini]
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2026-08-31 fix(firmware): power_save_mode none - the node was dozing off every few minutes
    Two drops in eleven minutes, each about thirty seconds, each self-healing. The
    ESP32 defaults to WIFI_PS_MIN_MODEM and sleeps between beacons; on this mesh
    that is enough to miss them and lose the connection. One missed sample is
    nothing, but the same rate across a three-hour print is dozens of gaps in
    exactly the data the enclosure test exists to produce.
    Radio stays on now. The node is mains-powered, so the cost is a few tens of mA
    and nothing else.
    Pushed over the air, which is the first real use of the OTA enabled an hour
    ago - the point of that change was precisely not having to open a hot enclosure
    for a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
    [chamber-baseline.csv]
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
